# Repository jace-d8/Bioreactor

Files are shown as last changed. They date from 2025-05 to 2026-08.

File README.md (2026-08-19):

# BioReactor

This is the firmware for an Arduino Nano ESP32 controlling a 3-reactor bioreactor rig. Each reactor has its own pH and ORP probe (Atlas Scientific EZO boards) and its own pair of dosing valves. The firmware reads the probes on a fixed cadence, automatically doses acid or oxidizer when readings fall below configured thresholds, displays live data on a 20x4 LCD, logs everything to an SD card, and exposes a joystick-driven menu for probe calibration and valve control.

## What it does

On a 2-second cadence, the firmware:

1. Reads pH and ORP from each of the 3 reactors over I2C (6 EZO probes total).
2. Compares each reading to its threshold. If a probe reads below threshold, the corresponding dosing valve is enqueued.
3. The MCP23017 I/O expander services the queue. One valve fires at a time, opens for 10 seconds, then closes. The next queued valve waits 12 seconds after the previous fired before it can open.
4. Each valve has a 60-second cooldown after firing before it can be re-enqueued.
5. Each valve has a rolling error window: if a valve fires more than its allowed trigger count inside a 60-minute window, I latch an error lock on that valve so it stops firing until the user resets it from the menu.
6. Sensor readings are written to the SD card every 2 seconds, and individual valve events get logged as message rows.

The LCD shows live readings when idle. The joystick (analog Y axis + push switch) opens the menu, where you can calibrate any probe and toggle valve control.

The timestamp is synced on boot via WiFi. Currently, the WiFi connection is set to be automatically connected to Washington State University Guest WiFi (WSU Guest), an open WiFi that requires adding the Arduino Nano ESP32 MAC address to a whitelist. WiFi SSID and time zone can be changed in config.h.

## Hardware

| Component | Role |
|---|---|
| Arduino Nano ESP32 | Main MCU |
| MCP23017 I/O expander | Drives the 6 dosing valves over I2C |
| 6x Atlas Scientific EZO boards | 3 pH + 3 ORP probes, I2C |
| LCM2004A 20x4 LCD | I2C display (on `Wire1`) |
| SD card module | SPI logging |
| 2-axis analog joystick with switch | Menu input |
| 6x N-channel power MOSFETs | Switch the dosing solenoids |
| 12V DC supply + LM2596 buck converters | Power for the logic side and the valves |

## Pin assignments

All in [`Config.h`](src/BioReactor/Config.h):

| Pin | Purpose |
|---|---|
| `PIN_Y = 2` | Joystick Y axis (analog) |
| `PIN_SW = 5` | Joystick push switch (active-low, `INPUT_PULLUP`) |
| `LCD_PIN_SDA = 6` | LCD I2C SDA (`Wire1`) |
| `LCD_PIN_SCL = 7` | LCD I2C SCL (`Wire1`) |
| `SD_CHIP_SELECT = 21` | SD card SPI chip-select |

MCP23017 outputs:

| MCP pin | Valve |
|---|---|
| 0 | pH1 dosing valve |
| 1 | ORP1 dosing valve |
| 2 | pH2 dosing valve |
| 3 | ORP2 dosing valve |
| 4 | pH3 dosing valve |
| 5 | ORP3 dosing valve |

EZO I2C addresses (declared in [`Config.h`](src/BioReactor/Config.h) under `EzoAddresses`, instantiated in [`BioReactor.ino`](src/BioReactor/BioReactor.ino)):

| Probe | I2C address |
|---|---|
| pH1 / pH2 / pH3 | 99 / 101 / 103 |
| ORP1 / ORP2 / ORP3 | 98 / 100 / 102 |

## Configurables

In [`Config.h`](src/BioReactor/Config.h):

```cpp
namespace Thresholds
{
  const float PH_MINIMUM = 6.3f;   // dose acid if pH drops below
  const int   ORP_MINIMUM = -400;  // dose oxidizer if ORP drops below
}

namespace BusSpeeds
{
  const uint32_t I2C_HZ    = 100000UL;    // both Wire and Wire1
  const uint32_t SD_SPI_HZ = 1000000UL;   // SD card SPI clock
}

namespace JoystickConfig
{
  const int           ANALOG_CENTER       = 1980;    // analogRead center value
  const int           ANALOG_DEADZONE     = 400;     // counts above/below center before scrolling
  const unsigned long SCROLL_DELAY_MS     = 200UL;   // throttle between menu scrolls
  const unsigned long SWITCH_DEBOUNCE_MS  = 300UL;   // joystick push-button debounce
}

namespace EzoAddresses
{
  const int PH[3]  = {99, 101, 103};
  const int ORP[3] = {98, 100, 102};
}

namespace TimingIntervals
{
  const unsigned long PROBE_READ_INTERVAL = 2000UL;             // probe polling
  const unsigned long SD_LOG_INTERVAL     = 2000UL;             // SD write cadence
  const unsigned long VALVE_COOLDOWN      = 60UL * 1000UL;      // per-valve refire lockout
  const unsigned long VALVE_ERROR_WINDOW  = 60UL*60UL*1000UL;   // rolling error window
  const int PH_VALVE_TRIGGER_LIMIT  = 10;                       // max pH fires per window
  const int ORP_VALVE_TRIGGER_LIMIT = 20;                       // max ORP fires per window
  const int MAX_VALVE_ERROR_HISTORY = 20;                       // ring buffer size
  const unsigned long BLINK_INTERVAL      = 300UL;              // menu cursor blink
  const unsigned long UI_RENDER_INTERVAL  = 80UL;               // menu redraw cap (~12.5 FPS)
  const unsigned long EZO_READ_INTERVAL   = 900UL;              // EZO state-machine tick
  const unsigned long QUEUE_TIMER         = 12000UL;            // min gap between queue pops
  const unsigned long VALVE_TIMER         = 10000UL;            // how long a valve stays open
}
```

`VALVE_TIMER` and `QUEUE_TIMER` are read by [`Mcp.cpp`](src/BioReactor/Mcp.cpp) and control the dosing valve on-time and the inter-valve gap. To shorten a dose (e.g. for tighter NaOH or air control), reduce `VALVE_TIMER` and keep `QUEUE_TIMER` at least as large.

## Module map

| File | What it does |
|---|---|
| [`BioReactor.ino`](src/BioReactor/BioReactor.ino) | Top-level setup + main loop. Owns the `ConfigState`, the probe arrays, and the valve trigger history. |
| [`Config.h`](src/BioReactor/Config.h) | All pins, thresholds, timings, and the shared `ConfigState` struct. |
| [`EzoBoard.{h,cpp}`](src/BioReactor/EzoBoard.h) | Wraps the Atlas EZO I2C driver. Runs an async read state machine (`Reading -> Waiting -> Receiving`), holds the last valid value, and exposes `sendCmd()` for calibration. |
| [`Mcp.{h,cpp}`](src/BioReactor/Mcp.h) | Owns the MCP23017 and the dosing-valve queue. `enqueue()` adds a valve, `update()` services the queue (open one valve, wait `VALVE_TIMER`, close it, gate the next pop on `QUEUE_TIMER`). |
| [`Sd.{h,cpp}`](src/BioReactor/Sd.h) | SPI SD logger. Auto-generates a fresh `LOG####.CSV` at boot, writes timestamped sensor rows and message rows for valve events and lockouts. |
| [`Lcd.{h,cpp}`](src/BioReactor/Lcd.h) | I2C 20x4 driver wrapper. Live data view and menu rendering helpers. |
| [`Joystick.{h,cpp}`](src/BioReactor/Joystick.h) | Reads the analog Y axis with a dead zone, debounces the switch, holds the current menu selection and max index. |
| [`Menu.{h,cpp}`](src/BioReactor/Menu.h) | UI state machine (`Idle / Calibrating / Valves / PhCalibration / OrpCalibration / Off`). Probe calibration writes EZO `Cal,low/mid/high/clear` commands; valve menu toggles dosing on/off and resets error locks. |
| [`Timer.{h,cpp}`](src/BioReactor/Timer.h) | Interval timer: `isReady()` returns true once `interval` has elapsed since last `reset()`. |
| [`ActionTimer.h`](src/BioReactor/ActionTimer.h) | One-shot cooldown timer. `start()` arms it, `done()` reports whether the duration has elapsed. |
| [`Wifi.h`](src/BioReactor/Wifi.h) | Connects the system to Wifi and syncs time at boot. Writes the status of time sync to the log file |
## Logging format

Every row in `LOG####.CSV` has the header `timestamp,pH1,ORP1,pH2,ORP2,pH3,ORP3,message`.

- **Sensor rows** (every `SD_LOG_INTERVAL`): the 6 readings populated, message blank.
- **Event rows** (valve fires, lockouts, boot): sensor columns blank, message column populated. Examples:

```
2026-05-13 14:02:11,6.273,-412,6.95,-380,6.84,-405,
2026-05-13 14:02:13,,,,,,,pH1 valve was triggered
2026-05-13 14:02:13,,,,,,,BOOT
2026-05-13 14:03:47,,,,,,,ORP2 valve locked
```

## Boot sequence

`setup()` brings up `Wire` (EZO + MCP bus), `Wire1` (LCD bus), the MCP, the LCD, SPI, the system clock (`configTime`), and the SD logger. If either the MCP or the SD card fails to initialize I show the failure on the LCD instead of starting the main loop. On success I write a `BOOT` row to the log.

## Menu navigation

Push the joystick at any time from the idle screen to open the menu.

| Screen | Actions |
|---|---|
| **Main** | Calibrate Probes / Valve Control / Exit |
| **Calibrate Probes** | Pick pH1/2/3 or ORP1/2/3 to enter probe calibration, or Done to go back |
| **pH calibration** | `Cal,low,4.00`, `Cal,mid,7.00`, `Cal,high,10.00`, `Cal,clear`, Done. A `*` marks buffers already calibrated for the active probe. The live pH reading is shown at the bottom. |
| **ORP calibration** | `Cal,222` (single-point at 222 mV) or Done. The live ORP reading is shown at the bottom. |
| **Valve Control** | Toggle valves enabled/disabled globally, reset any latched valve error locks, or return. |

## Naming Conventions

| Item | Style | Example |
|---|---|---|
| Classes | PascalCase | `EzoBoard` |
| Functions | camelCase | `sendCmd()` |
| Variables | camelCase | `orpValue` |
| Private Members | trailing `_` | `lastTrigger_` |
| Constants | ALL_CAPS | `MAX_BUFFER_SIZE` |

## Dependencies

Install through the Arduino IDE Library Manager unless noted otherwise:

- **SD** by SparkFun
- **Adafruit MCP23017 Arduino Library** by Adafruit
- **I2C_LCD** by Rob Tillaart
- **LiquidCrystal I2C** by Frank de Barbander
- **Ezo_I2c_lib** by Atlas-Scientific. This one is not in the Library Manager. I downloaded it from the Atlas-Scientific GitHub page and installed it manually into the Arduino IDE.

In the Arduino IDE, under **Tools**, set Pin Numbering to **"By GPIO number (legacy)"**.

## Building

Open [`src/BioReactor/BioReactor.ino`](src/BioReactor/BioReactor.ino) in the Arduino IDE, select the Arduino Nano ESP32 board, set the pin numbering option above, and upload.

---

Jace Dunn  
Kuangs Biotech Group, WSU  
jace.dunn@wsu.edu

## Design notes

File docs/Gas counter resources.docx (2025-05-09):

Please keep this document confidential

## General concept

- Gas production pushes the liquid in a U-tube to touch a liquid level sensor
- The liquid level sensor signals Arduino to trigger a solenoid valve to open to the atmosphere, which resets the liquid level
- Each liquid level change and reset is a consistent known volume. Counting the times that liquid level is triggered gives the gas production volume

Step 1:

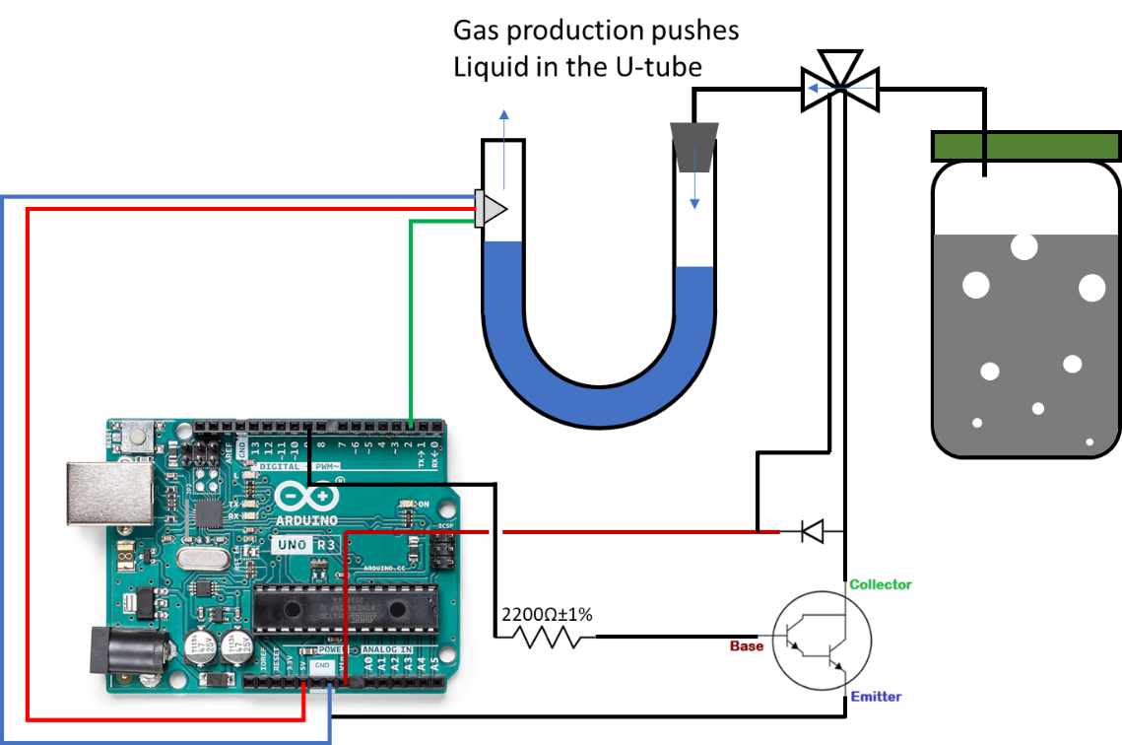
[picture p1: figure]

Step 2:

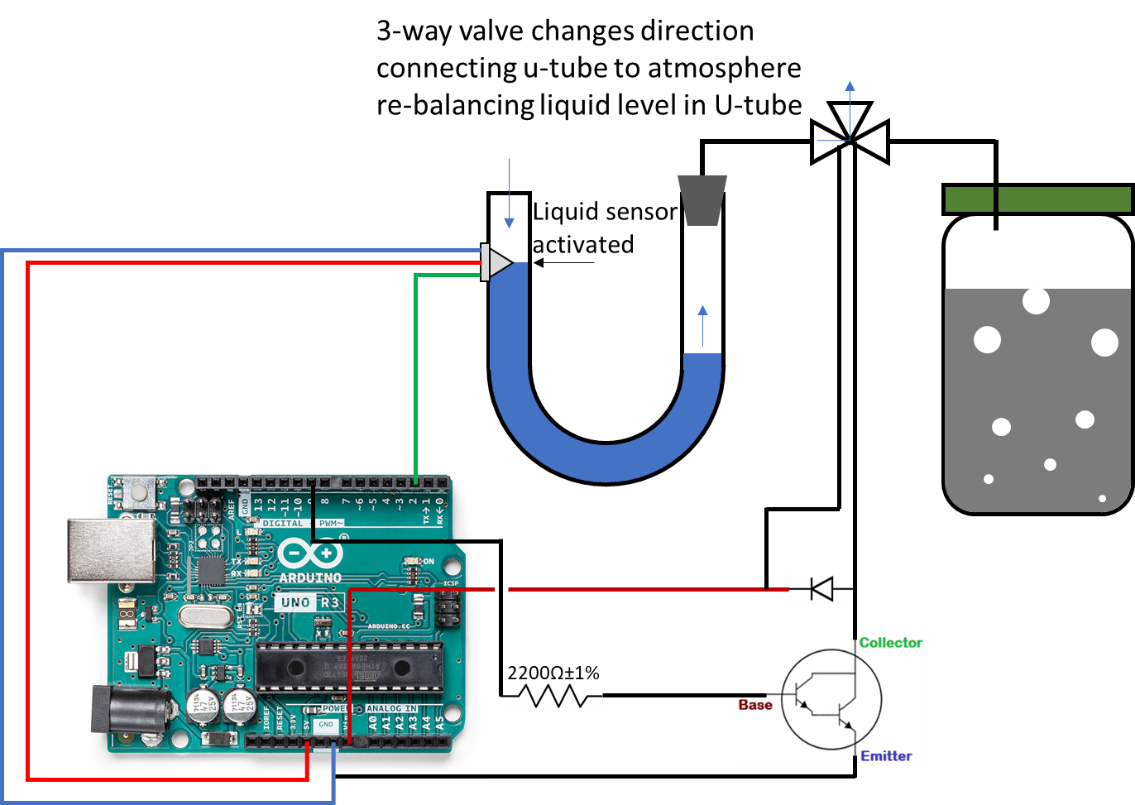
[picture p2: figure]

Step 3:

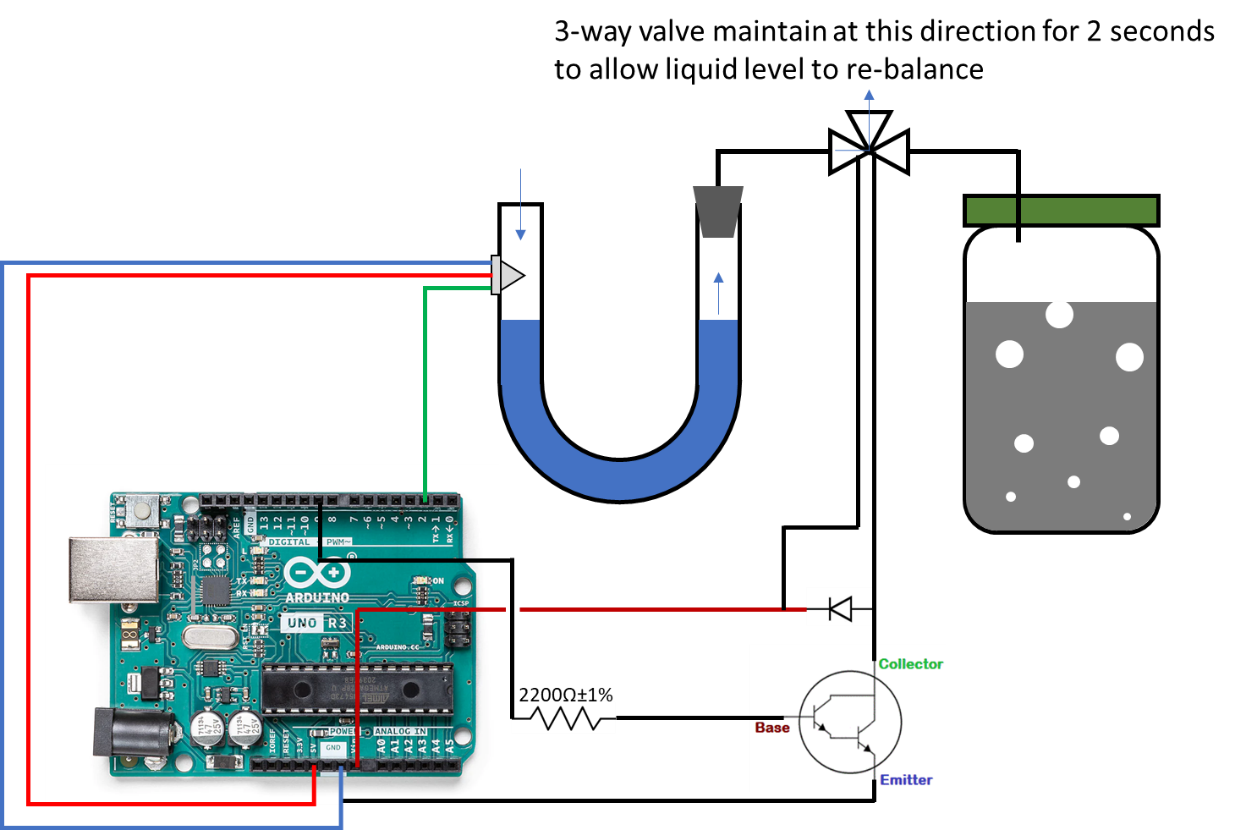
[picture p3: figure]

Step 4:

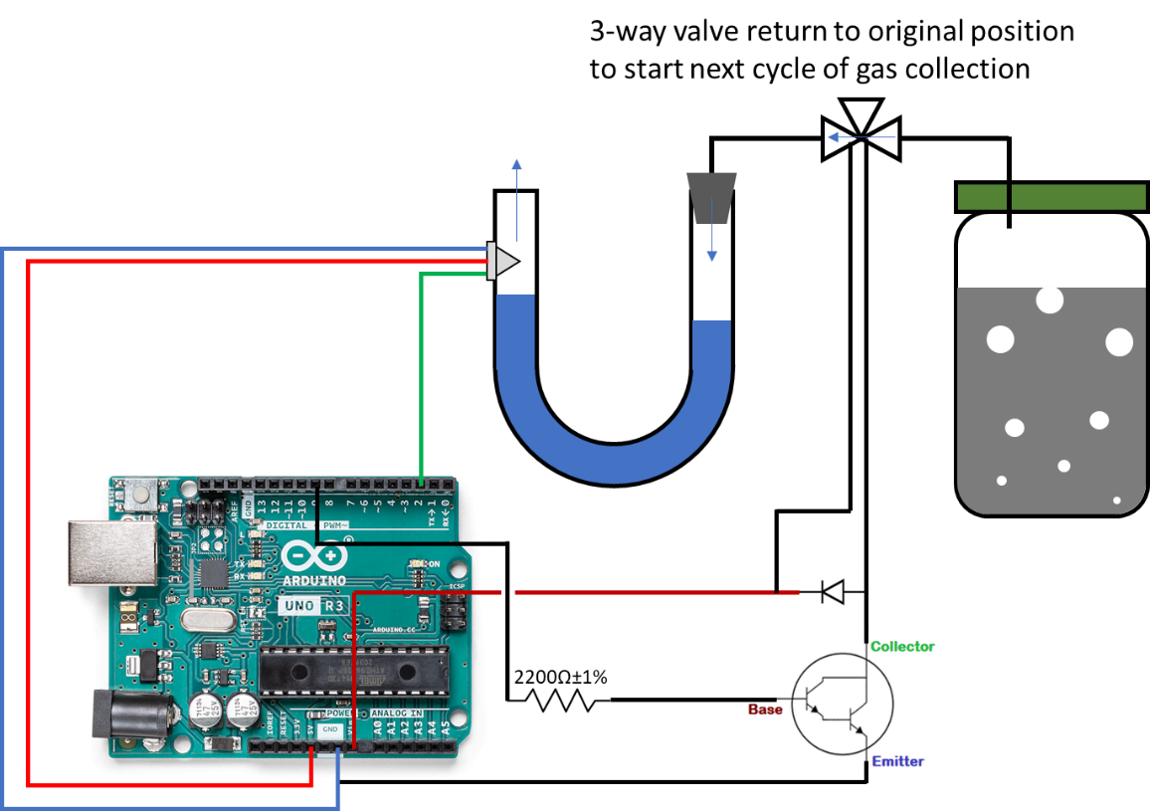
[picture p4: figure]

## Arduino board draft

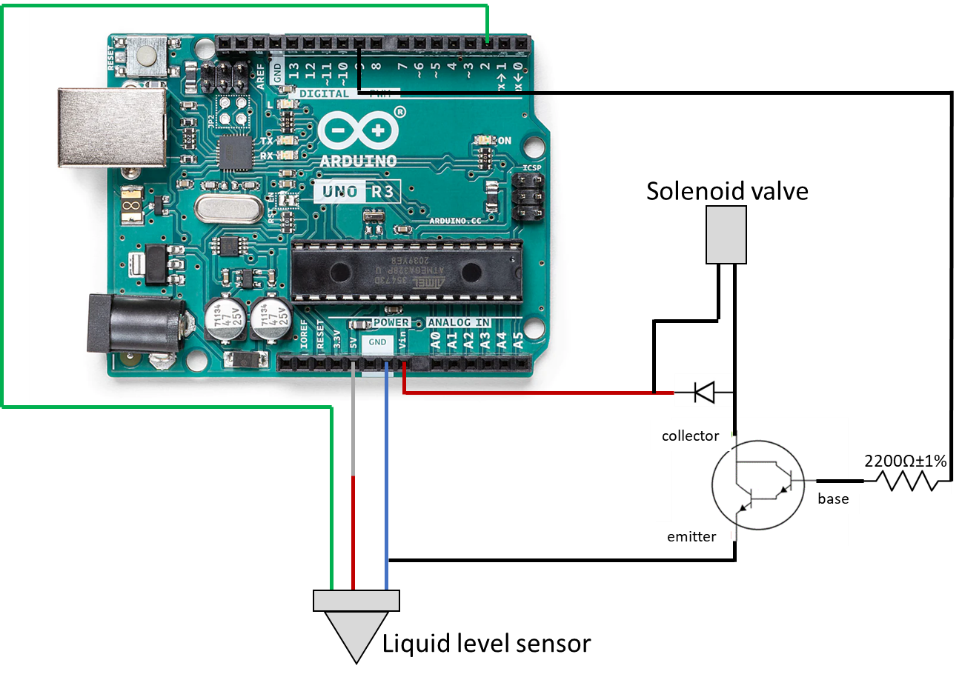
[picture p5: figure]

## Parts needed (some may be out of stock, need to find equivalents)

Must have:

- One level sensor ($25): Honeywell S&C - LLE101000 Adafruit: https://www.adafruit.com/product/3397
- One Solenoid Valve ($60): Asco 411M1312HV https://www.radwell.com/Buy/ASCO/ASCO/411M1312HV
- One Manifold ($28/pack of 4): clippart #15490-5 http://www.clippard.com/
- [Already in lab] One #10-32 to 1/8” ID Hose Fitting ($6/Pack of 10): #11752-3-PKG http://www.clippard.com/
- One Arduino Uno R3 (Atmega328 - assembled) ($24) #50 https://www.adafruit.com/
- One RGB LCD Shield Kit w/ 16x2 Character Display - Only 2 pins used! - NEGATIVE DISPLAY ($24) #714 https://www.adafruit.com/
- One TIP120 Power Darlington Transistors - 3 pack ($2.5) #976 https://www.adafruit.com/
- One 12 VDC 1000mA regulated switching power adapter - UL listed ($8) #798 https://www.adafruit.com/
- 1N4001 Diode - 10 pack ($1.5) #755 https://www.adafruit.com/
- Adafruit Perma-Proto Quarter-sized Breadboard PCB - Single ($3) #1608 https://www.adafruit.com/
- 2.2K Ohm Flameproof Electronic Metal Film Resistor ($8.67) Amazon: https://www.amazon.com/gp/product/B016D8CAB4/ref=crt_ewc_title_dp_3?ie=UTF8&psc=1&smid=ATVPDKIKX0DER

Good to have but optional

- One Quick-Disconnect Push-In Signal/Power Connector - Male ($26): McMaster #6134T43 https://www.mcmaster.com
- One Quick-Disconnect Push-In Signal/Power Connector - Female ($14): McMaster #6134T33 https://www.mcmaster.com
- Small Plastic Project Enclosure - Weatherproof with Clear Top ($10) #903 https://www.adafruit.com/

## Arduino Codes

// LCD library includes

#include <Wire.h>

#include <Adafruit_MCP23017.h>

#include <Adafruit_RGBLCDShield.h>

// Port definition

#define OPTO_PIN 2

#define VALVE_PIN 9

// LCD variable

Adafruit_RGBLCDShield lcd = Adafruit_RGBLCDShield();

// Other variables

int counter = 0;

bool open_valve = false;

void setup() {

// Initialize pin mode

pinMode(OPTO_PIN, INPUT);

pinMode(VALVE_PIN, OUTPUT);

Serial.begin(9600);

// set up the LCD's number of columns and rows:

lcd.begin(16, 2);

lcd.setBacklight(0x7);

lcd.setCursor(0,0);

lcd.print("Bio-Gas Counter");

lcd.setCursor(0,1);

lcd.print(counter);

//Serial.println(counter);

}

void loop() {

lcd.setCursor(0, 1);

// Read buttons status

uint8_t buttons = lcd.readButtons();

if (buttons & BUTTON_SELECT)

{

counter = 0;

lcd.print(counter);

}

if (buttons & BUTTON_LEFT) {

digitalWrite(VALVE_PIN,HIGH);

} else {

digitalWrite(VALVE_PIN,LOW);

}

gas_counter();

if(open_valve)

{

digitalWrite(VALVE_PIN,HIGH);

delay(2000);

digitalWrite(VALVE_PIN,LOW);

open_valve = false;

}

}

void gas_counter()

{

if(!digitalRead(OPTO_PIN))

{

counter++;

lcd.print(counter);

Serial.println(counter);

open_valve = true;

}

}

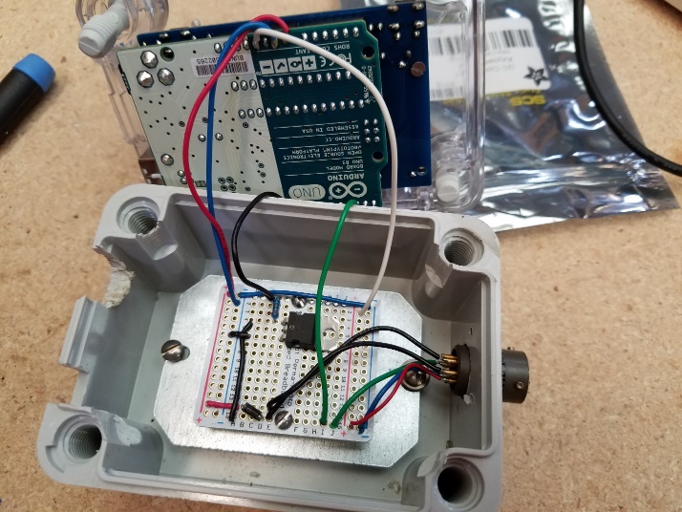
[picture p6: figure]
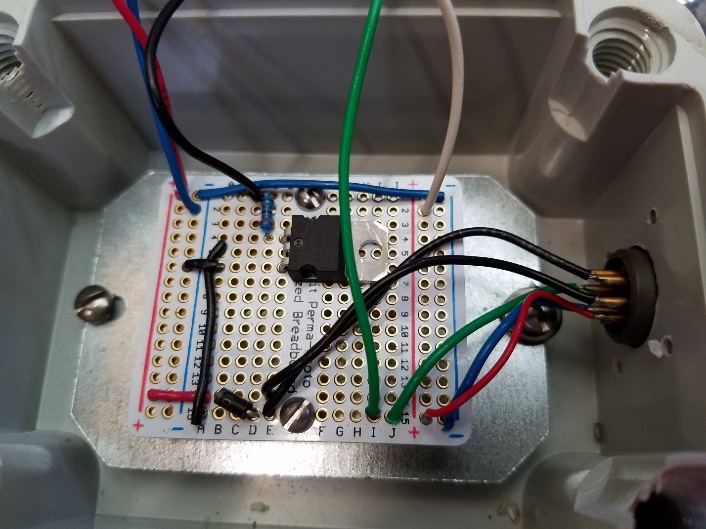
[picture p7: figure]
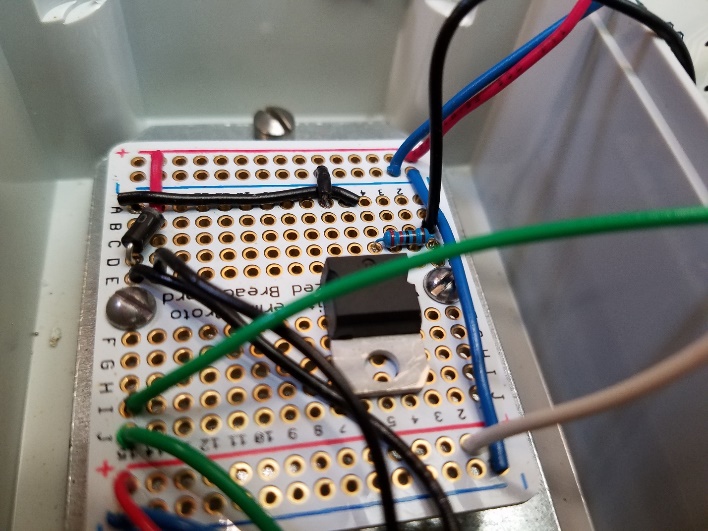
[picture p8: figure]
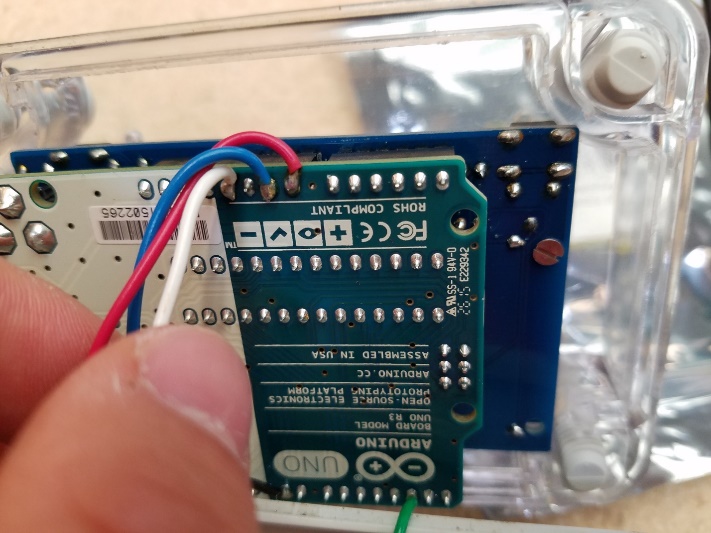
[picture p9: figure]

Overall reactor design for a two-phase system (just an idea for an old project, not necessary what we are developing here at WSU)

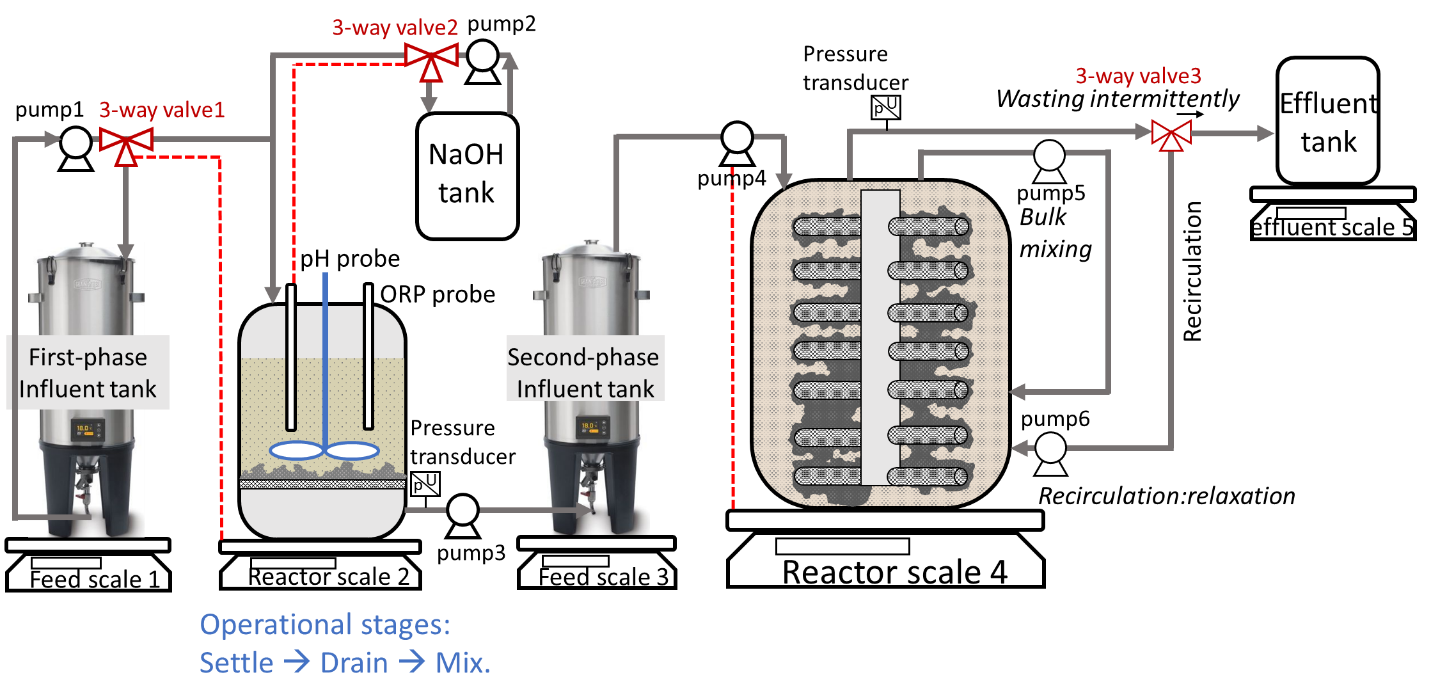
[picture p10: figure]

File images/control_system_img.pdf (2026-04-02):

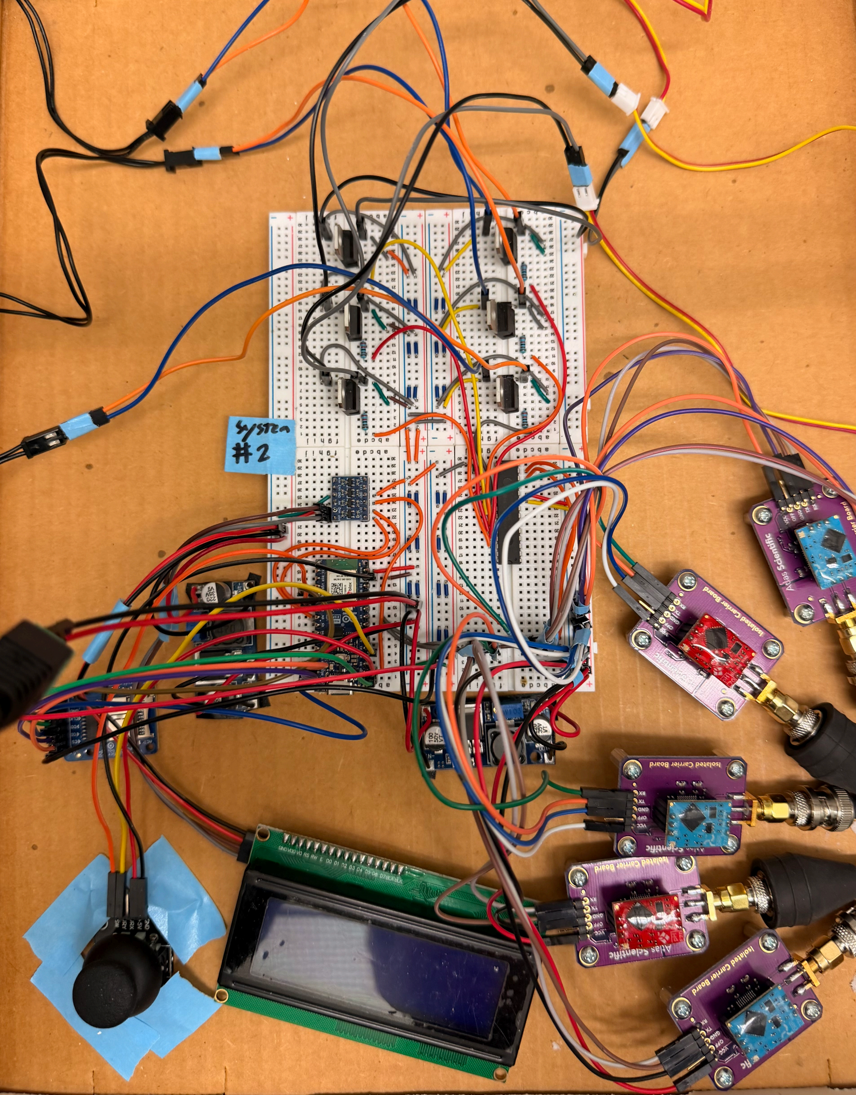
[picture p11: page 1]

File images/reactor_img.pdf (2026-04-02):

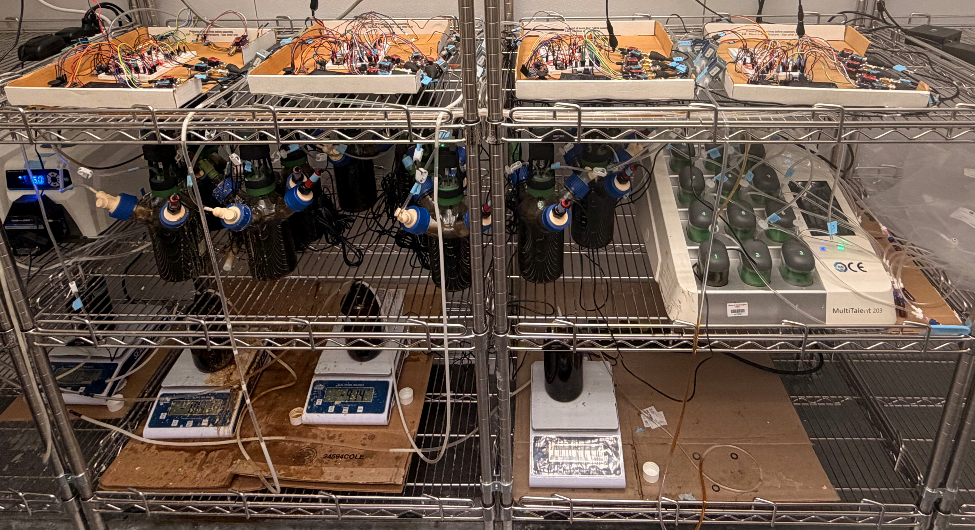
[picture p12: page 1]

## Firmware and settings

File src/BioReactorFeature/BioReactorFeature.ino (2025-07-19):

#include <Wire.h>
#include <Ezo_i2c.h>
#include <LiquidCrystal_I2C.h>
#include <SPI.h>
#include <SD.h>
#define UTC_OFFSET (-7 * 3600)  // For Pacific Time (PST). Use 0 for UTC, adjust as needed
#define PH_MIN 6.3
#define ORP_MIN -163


const int chipSelect = 10;
bool disableValves = false; 

File dataFile;


LiquidCrystal_I2C lcd(0x27, 20, 4);
char response[32];              // Buffer for response
String inputString = "";  // For manual commands

// Intervals
unsigned long lastReadTime = 0;
const unsigned long readInterval = 2000;  // 2 seconds
unsigned long lastHourTime = 0;
const unsigned long hourInterval = 3600000UL;  // 1 hour = 3,600,000 ms
unsigned long SDread = 0;
unsigned long pHread = 0;
unsigned long eLread = 0;
const unsigned long cooldownPeriod = 60000UL;

int phValveActivationCount = 0;
const int phValveMaxActivations = 5;
unsigned long lastPHactivation = 0;
const unsigned long phResetWindow = 15 * 60 * 1000UL; // 15 minutes to reset count

// Analog stick
const int SW_pin = D2; // D2: input for detecting whether the jotstick/button is pressed
const int Y_pin = A1; // A1: analog pin connected to Y output 

class Valve{
private: 
  int pin; 
  bool isOpen; 
  bool enable; 
  unsigned int startTime;
  const unsigned long openDuration; 
public: 
  Valve(int p, unsigned long d) : pin(p), openDuration(d), isOpen(false), enable(true), startTime(0) {}

  void open()
  {
    if(!isOpen && enable)
    {
      digitalWrite(pin, HIGH);
      startTime = millis(); 
      isOpen = true;
    } 
  }
  void update()
  {
    if (isOpen && (millis() - startTime >= openDuration))
    {
      digitalWrite(pin, LOW);
      isOpen = false;
    }
  }
  bool isValveOpen()
  {
    return isOpen;
  }
  void switchValve()
  {
    enable = !enable;
  }
  bool isEnabled()
  {
    return enable; 
  }
};

void logToSD(String message = "");


bool isCleared = false;
bool blinkState = true;
unsigned long lastBlinkTime = 0;
const unsigned long blinkInterval = 300;

// Probes
Ezo_board orp_sensor(98, "ORP");  
Ezo_board ph_sensor(99, "PH");  

// Probe Vals
float ph_val = 0.0; // I want these globally avaliable
int orp_val = 0; 

// Valves
Valve pHvalve(3, 10000);
Valve eLvalve(4, 4000);

// Note: I will consider using classes for further modularization

void setup()
{
  Serial.begin(9600);
  Wire.setClock(1000000);  // Set I2C speed to 100kHz


  pinMode(3, OUTPUT);  // For pHvalve
  pinMode(4, OUTPUT);  // For eLvalve
  
  // pinMode(LIQUID_SENSOR_PIN, INPUT);  
  // pinMode(GAS_SENSOR_PIN, INPUT); // Liquid detection sensor in U-tube
  // pinMode(VALVE_PIN, OUTPUT); // Controls state of 3 way valve

  //pinMode(SW_pin, INPUT); // Setup SW input
  //digitalWrite(SW_pin, HIGH);  // Reading button state: 1 = not pressed, 0 = pressed
  // The above two lines are for normal arduino, the below is for the nano esp32
  pinMode(SW_pin, INPUT_PULLUP);  
  //delay(100);

  Wire.begin();       
  lcd.init();
  lcd.backlight();
  lcd.setCursor(0, 0);
  lcd.print("Reading Probes");
  lcd.setCursor(0, 1);
  
  if (SD.begin(chipSelect)) 
  {
    lcd.print("SD initilzed");
    dataFile = SD.open("/data.csv", FILE_WRITE);
    dataFile.println("DATE,PH,ORP");
  }else
  {
    lcd.print("SD failed");
  }
  lcd.setCursor(0, 2);
  configTime(UTC_OFFSET, 0, "");  
  setTimeFromBuild();
}

void loop() 
{
  // is_liquid_detected = digitalRead(LIQUID_SENSOR_PIN); // will become true if sensor detects liquid 
  // is_gas_sensor = digitalRead(GAS_SENSOR_PIN); // is_open will be true if high voltage is read
  if (isCooldownOver(readInterval, lastReadTime)) 
  {
    ph_val = readPH();  // Convert char* to float
    orp_val = readORP();
    if(!isCleared)
    {
      lcd.clear(); // consider optimizing
      isCleared = true;
    }
    printData();   
    lastReadTime = millis();
  }

  if(isCooldownOver(SDread, 6000)) // 2 min, will change later
  {
    logToSD(); 
    SDread = millis(); 
  }
  if ((ph_val < PH_MIN) && isCooldownOver(pHread, cooldownPeriod)) 
  {
    pHvalve.open();
    logToSD("pH valve toggled"); 
    pHread = millis(); 

    // Check time since last activation
    if (millis() - lastPHactivation > phResetWindow) 
    {
      phValveActivationCount = 1;  // reset count
    }else 
    {
      phValveActivationCount++;  // count up
    }
    lastPHactivation = millis();
    if (phValveActivationCount >= phValveMaxActivations) 
    {
      displayWarning();  // trigger user intervention
      phValveActivationCount = 0;  // reset after warning
    }
  }
  if((orp_val < ORP_MIN) && isCooldownOver(eLread, cooldownPeriod)) // COOLDOWN DOES NOT CURRENTLY ACCOUNT FOR 10 SECONDS OF ACTIVATION, 50 second cooldown
  {
    eLvalve.open();
    logToSD("ORP valve toggled"); 
    eLread = millis(); 
  }
  if (isCooldownOver(lastHourTime, hourInterval))  
  {
    eLvalve.open();
    lastHourTime = millis();
  }

  pHvalve.update();
  eLvalve.update(); 
  lcdMenu();
}

bool isCooldownOver(unsigned long lastTime, unsigned long cooldown)
{
 return (millis() - lastTime >= cooldown);
}

float readPH()
{
  ph_sensor.send_cmd("R");         // Send read command
  delay(900);                      // Wait for the sensor to respond
  ph_sensor.receive_cmd(response, 32);  // Read response into buffer
  return atof(response);
}

float readORP()
{
  orp_sensor.send_cmd("R");
  delay(900);
  orp_sensor.receive_cmd(response, 32);
  return atof(response);
}


// void liquidLevelCheck(bool is_liquid_detected)
// {
//   if(is_liquid_detected)
//   {
//     Serial.println("Liquid detected");
//   }else
//   {
//     Serial.println("No liquid detected");
//   }
// }

// void gasCounter(bool is_gas_sensor)
// {
//   if (!is_gas_sensor && !valveOpen)
//   {
//     counter++;
//     Serial.println(counter);
//     digitalWrite(VALVE_PIN, HIGH);
//     valveStartTime = millis();
//     valveOpen = true;
//   }

//   if (valveOpen && millis() - valveStartTime >= interval) // maybe replace millis - valve with (lastprint)
//   {
//     digitalWrite(VALVE_PIN, LOW);
//     valveOpen = false;
//   }
// }

void lcdMenu()
{
  bool calibrateMenu = false;
  int selectedItem = -1;  // 0 = pH Probe 1, 1 = pH Probe 2...
  if(!digitalRead(SW_pin))
  {
    delay(200);  // debounce
    calibrateMenu = true; 
    selectedItem = 0;
    lcd.clear();
    while(calibrateMenu)
    {
      analogControl(selectedItem);
      updateGlobalBlink();

      lcd.setCursor(0, 0);
      lcd.print("Calibrate Probe:");

      printMenu(selectedItem);
      isPressed(calibrateMenu, selectedItem);
    }
  }
}

void printMenu(int selectedItem)
{
    printMenuItem(0, 1, "pH 1", 0, selectedItem);
    printMenuItem(0, 2, "pH 2", 1, selectedItem);
    printMenuItem(0, 3, "pH 3", 2, selectedItem);
    printMenuItem(6, 1, "ORP 1", 3, selectedItem);
    printMenuItem(6, 2, "ORP 2", 4, selectedItem);
    printMenuItem(6, 3, "ORP 3", 5, selectedItem);
    if(disableValves)
    {
      printMenuItem(13, 1, "Vl ON", 6, selectedItem);
    }else
    {
      printMenuItem(13, 1, "Vl OFF", 6, selectedItem);
    }

    printMenuItem(13, 2, "Done", 7, selectedItem);
}

void isPressed(bool &calibrateMenu, int selectedItem) // later to be optimized when multiple probes are utilized
{
  if (!digitalRead(SW_pin)) 
  {
    delay(200);  // debounce
    while (!digitalRead(SW_pin));  // wait until released
    if (selectedItem == 0)
    {
      calibrateProbePH();
    }else if(selectedItem == 3)
    {
      calibrateProbeORP();
    }else if(selectedItem == 6)
    {
      disableValves = !disableValves;
      pHvalve.switchValve();
      eLvalve.switchValve();
      lcd.clear();
      if(disableValves)
      {
        lcd.print("Valves off");
      }else
      {
        lcd.print("Valves on");
      }
      delay(600);
      lcd.clear();
    }else if (selectedItem == 7) 
    {
      calibrateMenu = false;
      lcd.clear();
    }
  }
}

void analogControl(int& selectedItem)
{
  int yVal = analogRead(Y_pin);

  // Dead zone around the resting value (~1980)
  const int deadZone = 400;

  if (yVal < 1980 - deadZone) 
  {  // Up
    if (selectedItem > 0)
      selectedItem--;
    delay(200); // Debounce
  } else if (yVal > 1980 + deadZone) 
  {  // Down
    if (selectedItem < 7)  // 6 is your "Done" item
      selectedItem++;
    delay(200); // Debounce
  }
}


void updateGlobalBlink() {
  unsigned long currentMillis = millis();
  if (currentMillis - lastBlinkTime >= blinkInterval) {
    blinkState = !blinkState;
    lastBlinkTime = currentMillis;
  }
}

void printMenuItem(int col, int row, const char* label, int itemIndex, int selectedIndex) {
  lcd.setCursor(col, row);
  if (itemIndex == selectedIndex && blinkState) {
    lcd.print("      ");  // Blank line to simulate blinking
  } else {
    lcd.print(label);
  }
}

void calibrateProbePH() {
  int bufferSelection = 0;
  bool bufferCalibrated[3] = {false, false, false};
  bool selecting = true;

  lcd.clear();

  while (selecting) {
    analogControl(bufferSelection);
    updateGlobalBlink();

    // ph_val = readPH();   putting this on hold

    lcd.setCursor(0, 0);
    lcd.print("Select Buffer:");
    printMenuItem(0, 1, "pH 4", 0, bufferSelection);
    printMenuItem(0, 2, "pH 7", 1, bufferSelection);
    printMenuItem(0, 3, "pH 10", 2, bufferSelection);
    printMenuItem(10, 1, "Clear", 3, bufferSelection);  
    printMenuItem(10, 2, "Done", 4, bufferSelection);
    lcd.setCursor(10, 3);
    // lcd.print("pH: ");
    // lcd.print(ph_val, 3); // to the thousandths


    if (bufferCalibrated[0]) lcd.setCursor(6, 1), lcd.print("*");
    if (bufferCalibrated[1]) lcd.setCursor(6, 2), lcd.print("*");
    if (bufferCalibrated[2]) lcd.setCursor(6, 3), lcd.print("*");

    
    if (!digitalRead(SW_pin)) {
      delay(200);
      while (!digitalRead(SW_pin)); 

      switch (bufferSelection) {
        case 0:
          ph_sensor.send_cmd("Cal,low,4.00");
          bufferCalibrated[0] = true;
          break;
        case 1:
          ph_sensor.send_cmd("Cal,mid,7.00");
          bufferCalibrated[1] = true;
          break;
        case 2:
          ph_sensor.send_cmd("Cal,high,10.00");
          bufferCalibrated[2] = true;
          break;
        case 3: 
          ph_sensor.send_cmd("Cal,clear");
          bufferCalibrated[0] = bufferCalibrated[1] = bufferCalibrated[2] = false;
          lcd.clear();
          lcd.print("Calibration Cleared");
          delay(1500);
          lcd.clear();
          break;
        case 4:  
          lcd.clear();
          lcd.print("Returning");
          delay(1000);
          lcd.clear();
          selecting = false;
          break;
      }
    }
    if (bufferCalibrated[0] && bufferCalibrated[1] && bufferCalibrated[2]) 
    {
      lcd.clear();
      lcd.print("All Calibrated!");
      delay(800);
      lcd.clear();
      selecting = false;
    }
  }
}

void calibrateProbeORP()
{
  int selectedItem = 0;  // Only one item for now, but this keeps it consistent
  bool selecting = true;
  int lastPrint = 0;
  lcd.clear();

  while (selecting) {
    analogControl(selectedItem);
    updateGlobalBlink();

    // if(isCooldownOver(lastPrint, 4000)) // 4 second cooldown
    // {
    //   orp_val = readORP(); putting this idea on hold
    // }
    lcd.setCursor(0, 0);
    lcd.print("Calibrate when ready");

    printMenuItem(0, 1, "Cal", 0, selectedItem);
    printMenuItem(0, 2, "Done", 1, selectedItem);

    lcd.setCursor(5, 1);

    // lcd.print("ORP: ");
    // lcd.print(orp_val, 0);
    // lcd.print(" mV     ");
    


    if (!digitalRead(SW_pin)) {
      delay(200);  // Debounce
      while (!digitalRead(SW_pin));  // Wait until released
      switch(selectedItem)
      {
        case 0:
          orp_sensor.send_cmd("Cal,222");
          lcd.clear();
          lcd.print("Calibrated at 222mV");
          delay(1000);
          selecting = false;
          lcd.clear();
          break;
        case 1: 
          lcd.clear();
          lcd.print("Returning");
          delay(1000);
          selecting = false;
          lcd.clear();
      }
    }
  }
}

void setTimeFromBuild()
{
  struct tm tm; // std C++ time struct
  if (strptime(__DATE__ " " __TIME__, "%b %d %Y %H:%M:%S", &tm)) // Taking compile time and parsing it for tm 
   {
    time_t t = mktime(&tm); // unix timestamp 
    struct timeval now = { .tv_sec = t }; // std C++ time struct, seconds since 1970, so esp32 can count further
    settimeofday(&now, nullptr); // setting esp32 clock to laptop time

    char buf[32];
    strftime(buf, sizeof(buf), "%Y-%m-%d %H:%M:%S", localtime(&t)); // takes seconds and converts to human readable time
    lcd.print(buf);
  } else 
  {
    lcd.print("Failed to parse build time");
  }
}

void logToSD(String message)
{
  time_t now = time(nullptr);
  struct tm* timeinfo = localtime(&now); // reads our updated esp32 time

  if (!dataFile) 
  {
    lcd.print("File failed\n");
    return;
  }
  if (message.length() == 0) 
  {
    dataFile.printf("%04d-%02d-%02d %02d:%02d:%02d,%.3f,%d\n", // logging time from esp32
                    timeinfo->tm_year + 1900,
                    timeinfo->tm_mon + 1,
                    timeinfo->tm_mday,
                    timeinfo->tm_hour,
                    timeinfo->tm_min,
                    timeinfo->tm_sec,
                    ph_val,
                    orp_val);
    dataFile.flush();
  }
  else
  {
    dataFile.printf("%04d-%02d-%02d %02d:%02d:%02d,%s\n",
                    timeinfo->tm_year + 1900,
                    timeinfo->tm_mon + 1,
                    timeinfo->tm_mday,
                    timeinfo->tm_hour,
                    timeinfo->tm_min,
                    timeinfo->tm_sec,
                    message.c_str());   
  }         
}

void displayWarning()
{
  bool bypass_warning = false; 
  lcd.clear();
  pHvalve.switchValve();
  while(!bypass_warning)
  {
    updateGlobalBlink();

    lcd.setCursor(0, 0);
    lcd.print("WARNING:");
    
    lcd.setCursor(0, 1);
    lcd.print("pH valve overuse");

    printMenuItem(0, 2, "Unlock?", 0, 0);

    if (!digitalRead(SW_pin)) 
    {
      delay(200);
      while (!digitalRead(SW_pin)); 
      bypass_warning = true;
      lcd.clear();
      lcd.print("System Unlocked");
      delay(700);
      lcd.clear();
      pHvalve.switchValve();
    }
  }
}

void printData()
{
    lcd.setCursor(0, 0);
    lcd.print("pH: ");
    lcd.print(ph_val, 3); // To the thousandths
    lcd.print("     "); // Clear leftover digits

    lcd.setCursor(0, 1);
    lcd.print("ORP: ");
    lcd.print(orp_val, 0);
    lcd.print(" mV     ");

    // lcd.setCursor(0, 2);
    // lcd.print("Count: ");
    // lcd.print(counter);  
    // lcd.print("     ");
}

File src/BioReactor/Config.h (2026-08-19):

#pragma once
#include <Arduino.h>

namespace PinConfigurations
{
  const int PIN_SW = 5;//Joystick switch pin//
  const int PIN_Y = 2;//Joystick y-axis pin//
  const int PH_VALVE_PIN = 10;//pH valve pin, no longer used since all valves are handled in MCP//
  const int ORP_VALVE_PIN = 17;//ORP valve pin, no longer used since all valves are handled in MCP// 
  const int LCD_PIN_SDA = 6;//LCD SDA pin//
  const int LCD_PIN_SCL = 7;//LCD SCL pin//
  const int SD_CHIP_SELECT = 21;//SD chip select pin//
}

namespace ThresholdDefaults
{
  const float PH_MINIMUM = 4.1f; //normally 6.3, set to 4.1 for testing//
  const float ORP_MINIMUM = -400.0f; // use -400 for microaerobic trials, use -1000 for anaerobic trials //
}

namespace ThresholdLimits
{
  const float PH_MIN = 4.0f;
  const float PH_MAX = 9.0f;
  const float PH_STEP = 0.1f;
  const float ORP_MIN = -500.0f;
  const float ORP_MAX = 500.0f;
  const float ORP_STEP = 5.0f;
}

namespace BusSpeeds//Bus speeds for I2C and SPI//
{
  const uint32_t I2C_HZ = 100000UL;//I2C bus speed//
  const uint32_t SD_SPI_HZ = 1000000UL;//SPI bus speed for SD card//
}

namespace JoystickConfig//Joystick configuration//
{
  const int ANALOG_CENTER = 1980;//Analog center value//
  const int ANALOG_DEADZONE = 800;//Analog deadzone value, within which the joystick is considered to be in the center position//
  const unsigned long SCROLL_DELAY_MS = 200UL;//Scroll delay time, to prevent rapid scrolling//
  const unsigned long SWITCH_DEBOUNCE_MS = 300UL;//Switch debounce time, to prevent rapid button presses//
}

namespace EzoAddresses//EZO addresses for the 3 probes//
{
  const int PH[3]  = {99, 101, 103};//pH probe addresses//
  const int ORP[3] = {98, 100, 102};//ORP probe addresses//
}

namespace TimingIntervals
{
  const unsigned long PROBE_READ_INTERVAL = 2000UL;//*2 seconds between probe reads//
  const unsigned long SD_LOG_INTERVAL = 30000UL;//*30 seconds between SD card logs//

  const unsigned long VALVE_COOLDOWN = 60UL * 1000UL;//*60 s cooldown between valve triggers//

  // Separate error-lock windows for pH and ORP valves.
  // Each defines how far back the trigger history is scanned when deciding
  // whether a valve has exceeded its trigger limit.  Having two independent
  // constants means the pH and ORP windows can be tuned separately in
  // Config.h without affecting each other.
  const unsigned long PH_VALVE_ERROR_WINDOW  = 60UL * 60UL * 1000UL;//*1 hour window for pH error-locking//
  const unsigned long ORP_VALVE_ERROR_WINDOW = 60UL * 60UL * 1000UL;//*1 hour window for ORP error-locking//

  const int MAX_VALVE_ERROR_HISTORY = 99;

  const unsigned long BLINK_INTERVAL = 300UL;//*300 ms between blink state changes//
  const unsigned long UI_RENDER_INTERVAL = 80UL;//*80 ms between UI renders//

  const unsigned long EZO_READ_INTERVAL = 900UL;//*900 ms between probe reads//
  const unsigned long EZO_EXPORT_IMPORT_DELAY = 1800UL; //*1800 ms delay per calibration data import chunk//
  const unsigned long EZO_CAL_SETTLE_MS = 1000UL; //*1000 ms gap after a Cal command before export begins; the EZO has no command queue so Export must not be sent until Cal has fully executed (~900 ms)//

  // Default valve open durations (seconds); editable at runtime via Thresholds menu//
  const int PH_VALVE_TIMER_SEC  = 10;//*10 s default pH valve open duration//
  const int ORP_VALVE_TIMER_SEC = 10;//*10 s default ORP valve open duration//

  // Queue timers are always valve-timer + 2 s; recomputed at runtime in BioReactor.ino//
  // These compile-time constants give the startup values before any menu edits.//
  const unsigned long PH_VALVE_TIMER  = (unsigned long)PH_VALVE_TIMER_SEC  * 1000UL;
  const unsigned long ORP_VALVE_TIMER = (unsigned long)ORP_VALVE_TIMER_SEC * 1000UL;
  const unsigned long PH_QUEUE_TIMER  = PH_VALVE_TIMER  + 2000UL;
  const unsigned long ORP_QUEUE_TIMER = ORP_VALVE_TIMER + 2000UL;

  // How long a reading must stay below threshold before the valve is queued//
  const unsigned long VALVE_BELOW_THRESHOLD_MS = 10000UL;//*10 s dwell before queueing//
}

namespace TriggerLimitDefaults
{
  const int PH_VALVE_TRIGGER_LIMIT  = 5;//max 5 pH valve triggers per hour (default)//
  const int ORP_VALVE_TRIGGER_LIMIT = 73;//max 73 ORP valve triggers per hour (default)//
}

namespace TriggerLimitBounds
{
  const int MIN  = 1;
  const int MAX  = 99;
  const int STEP = 1;
}

namespace ValveTimerBounds
{
  const int MIN_SEC  = 1;
  const int MAX_SEC  = 18;  //cannot exceed 18 seconds or it will conflict with the 1min cooldown.//
  const int STEP_SEC = 1;
}

namespace ValveMappings//Mapping of MCP pins to valves//
{
  const int TOTAL_VALVES = 6;
}

namespace CalibrationStorage
{
  const char FILE_PATH[] = "/CALIB.CSV";
  const size_t EXPORT_PAYLOAD_MAX = 160;
}
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

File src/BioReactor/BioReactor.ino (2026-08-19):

#include <Wire.h>
#include <SPI.h>
#include <string.h>
#include "Config.h"
#include "Mcp.h"
#include "EzoBoard.h"
#include "Lcd.h"
#include "Sd.h"
#include "Timer.h"
#include "ActionTimer.h"
#include "Menu.h"
#include "Wifi.h"

ConfigState config;
WifiTime wifiTime;//non-blocking WiFi connect + NTP sync, keeps the clock correct across power cycles//

EzoBoard orpSensors[3] = {//set up ORP sensors (3 probes)//
  EzoBoard(EzoAddresses::ORP[0], "ORP"),
  EzoBoard(EzoAddresses::ORP[1], "ORP"),
  EzoBoard(EzoAddresses::ORP[2], "ORP")
};

EzoBoard phSensors[3] = {//set up pH sensors (3 probes)//
  EzoBoard(EzoAddresses::PH[0], "pH"),
  EzoBoard(EzoAddresses::PH[1], "pH"),
  EzoBoard(EzoAddresses::PH[2], "pH")
};

Mcp mcp;//set up MCP controller (controls the valves)//
Lcd lcd(0x27, &Wire1);//set up LCD display//
SdLogger sd;//set up SD card logger//
Menu menu(&config, phSensors, orpSensors, lcd, sd, wifiTime);

Timer probeTimer(TimingIntervals::PROBE_READ_INTERVAL);//*2 s between probe reads//
Timer sdLogTimer(TimingIntervals::SD_LOG_INTERVAL);//*2 s between SD card logs//

bool queued[ValveMappings::TOTAL_VALVES] = { false };//valve already in queue guard//

ActionTimer cooldown[ValveMappings::TOTAL_VALVES] = {
  ActionTimer(TimingIntervals::VALVE_COOLDOWN),
  ActionTimer(TimingIntervals::VALVE_COOLDOWN),
  ActionTimer(TimingIntervals::VALVE_COOLDOWN),
  ActionTimer(TimingIntervals::VALVE_COOLDOWN),
  ActionTimer(TimingIntervals::VALVE_COOLDOWN),
  ActionTimer(TimingIntervals::VALVE_COOLDOWN)
};//One 60 s cooldown timer per valve; started when a valve is queued.//

// ── Dwell timers ──────────────────────────────────────────────────────────────
// Each valve gets its own ActionTimer.  The timer is started (or kept running)
// while the reading is below the threshold, and reset as soon as the reading
// rises above it.  A valve is only queued once the dwell timer has expired,
// i.e. the reading has been continuously below threshold for at least
// TimingIntervals::VALVE_BELOW_THRESHOLD_MS milliseconds.
ActionTimer dwellTimer[ValveMappings::TOTAL_VALVES] = {
  ActionTimer(TimingIntervals::VALVE_BELOW_THRESHOLD_MS),
  ActionTimer(TimingIntervals::VALVE_BELOW_THRESHOLD_MS),
  ActionTimer(TimingIntervals::VALVE_BELOW_THRESHOLD_MS),
  ActionTimer(TimingIntervals::VALVE_BELOW_THRESHOLD_MS),
  ActionTimer(TimingIntervals::VALVE_BELOW_THRESHOLD_MS),
  ActionTimer(TimingIntervals::VALVE_BELOW_THRESHOLD_MS)
};

// Tracks whether each valve's dwell timer is currently running (started but
// not yet done).  Prevents re-starting the timer on every loop iteration.
bool dwellRunning[ValveMappings::TOTAL_VALVES] = { false };

//History of open times for error-locking (too many opens in *1 hour).//
unsigned long valveTriggerTimes[ValveMappings::TOTAL_VALVES][TimingIntervals::MAX_VALVE_ERROR_HISTORY] = {};
int valveTriggerCounts[ValveMappings::TOTAL_VALVES] = {};

// ── tryQueueValve ─────────────────────────────────────────────────────────────
// condition = true  → reading is below threshold right now.
// A valve is only actually queued once the dwell timer says the reading has
// been below threshold for at least VALVE_BELOW_THRESHOLD_MS continuously.
bool tryQueueValve(int valveId, bool condition)
{
  if (!condition)
  {
    // Reading is fine — reset the dwell timer so the clock starts fresh
    // if it dips below threshold again later.
    dwellTimer[valveId].stop();
    dwellRunning[valveId] = false;
    return false;
  }

  // Reading is below threshold.  Kick off the dwell timer on the first
  // low reading.  dwellRunning[] tracks whether we have already called
  // start() so we do not reset a running timer on every loop iteration.
  if (!dwellRunning[valveId])
  {
    dwellTimer[valveId].start();
    dwellRunning[valveId] = true;
  }

  // Not yet held below threshold long enough.
  if (!dwellTimer[valveId].done()) return false;

  // Dwell satisfied — now apply the usual guards.
  if (config.valvesDisabled)               return false;
  if (queued[valveId])                     return false;
  if (config.valveErrorLocked[valveId])    return false;
  if (!cooldown[valveId].done())
  {
    // Cooldown still running — reset dwell so the 5 s must elapse
    // again from scratch once the cooldown is over.
    dwellTimer[valveId].stop();
    dwellRunning[valveId] = false;
    return false;
  }
  if (!mcp.enqueue(valveId))               return false;

  cooldown[valveId].start();
  queued[valveId] = true;

  // Reset dwell so the timer must expire again for the next trigger.
  dwellTimer[valveId].stop();
  dwellRunning[valveId] = false;

  return true;
}

// ── recordValveTrigger ────────────────────────────────────────────────────────
void recordValveTrigger(int valveId)
{
  int& count = valveTriggerCounts[valveId];

  if (count < TimingIntervals::MAX_VALVE_ERROR_HISTORY)
  {
    valveTriggerTimes[valveId][count++] = millis();
  }
  else
  {
    for (int i = 1; i < TimingIntervals::MAX_VALVE_ERROR_HISTORY; ++i)
      valveTriggerTimes[valveId][i - 1] = valveTriggerTimes[valveId][i];
    valveTriggerTimes[valveId][TimingIntervals::MAX_VALVE_ERROR_HISTORY - 1] = millis();
  }

  // Use runtime-editable limits from ConfigState.
  const bool isPh  = (valveId % 2 == 0);
  const int  limit = isPh ? config.phMaxTrig : config.orpMaxTrig;

  // Select the error window for the valve type being checked.
  // pH and ORP now have independent windows defined in Config.h so they
  // can be tuned separately without affecting each other.
  const unsigned long errorWindow = isPh
    ? TimingIntervals::PH_VALVE_ERROR_WINDOW
    : TimingIntervals::ORP_VALVE_ERROR_WINDOW;

  if (count >= limit)
  {
    unsigned long oldest = valveTriggerTimes[valveId][count - limit];
    if (millis() - oldest < errorWindow)
    {
      if (!config.valveErrorLocked[valveId])
      {
        config.valveErrorLocked[valveId] = true;
        sd.logValveLocked(valveId);
      }
    }
  }
}

// ── resetValveErrors ──────────────────────────────────────────────────────────
void resetValveErrors()
{
  for (int i = 0; i < ValveMappings::TOTAL_VALVES; ++i)
  {
    config.valveErrorLocked[i] = false;
    valveTriggerCounts[i]      = 0;
    queued[i]                  = false;
    dwellTimer[i].stop();
    dwellRunning[i]            = false;
    // Stop the cooldown so valves can re-trigger immediately after a reset.
    // ActionTimer::done() returns true when not running, so stop() is all
    // that is needed — no separate "clear" is required.
    cooldown[i].stop();

    for (int j = 0; j < TimingIntervals::MAX_VALVE_ERROR_HISTORY; ++j)
      valveTriggerTimes[i][j] = 0;
  }

  mcp.resetState(queued);
  config.requestResetErrors = false;
}
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

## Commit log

2025-05-09 Reconstructing folder structure
    [BioReactor.fzz]
2025-05-09 Fix: remove submodule and add Code as regular folder
    [BioReactor.ino, pHCode.ino, sketch_may1a.ino]
2025-05-16 Merged feature
    [BioreactorPCB.kicad_pcb, BioreactorPCB.kicad_sch]
2025-05-25 Added calibration menu logic, pre-modularization
2025-05-29 Updated LCD menu
    [BioreactorPCB.kicad_sch]
2025-05-29 Moved everything over to arduino nano
2025-06-16 Pushing code for selenoid valve
    [BioreactorPCB.kicad_sch]
2025-06-25 Altered joystick setup for nano esp32
2025-06-25 Adjusted analog range for 3.3V bounds
2025-06-27 Updated LCD logic and added orp calibration
2025-06-30 Added basic valve logic and sd/time code
2025-07-02 Added a valve class
2025-07-19 Added SD valve updates, fixed orp done button, added valve error based on count, refactored feature2 code
    [BioReactorFeature.ino, Config.h]
2025-07-29 Replaced global variables with a stuct
    [Config.h, Sd.cpp]
2025-07-29 Created timer class
2025-07-29 Refactored loop using timer
2025-07-29 Reworked global blink function
    [Config.h]
2025-07-29 More refactoring, generated a test message function to replace delays
    [Config.h]
2025-08-05 Fixed bootup lcd format, removed some debounce delays, printed cal menu
    [Config.h, Sd.cpp]
2025-08-08 Added fsm to probes for non blocking logic
2025-08-08 Renamed state to probe state, fixed brace indentation, removed menu globals
2025-08-29 fixed menu exit button
2025-09-03 Fixed orp probe type issue, reformatted src
    [BioReactor.ino, BioReactorFeature.ino, Config.h]
2025-09-03 Temp rename to force case change
    [BioReactor.fzz, BioreactorPCB.kicad_pcb, BioreactorPCB.kicad_sch]
2025-09-03 Rename Diagrams -> diagrams (lowercase)
    [BioReactor.fzz, BioreactorPCB.kicad_pcb, BioreactorPCB.kicad_sch]
2025-09-22 Fixed valve issues
2025-11-25 probe expansion
2025-11-27 valve updates
2026-02-17 updated reactor diagram
    [BioReactor.fzz]
2026-02-27 Began standardized commenting, fixed lcd ph display issue
    [Sd.cpp, Sd.h]
2026-04-17 Added reset state after error lockout
    [BioReactor.fzz]
2026-04-23 Update README.md
    Added required libraries and Pin Numbering setting.
2026-08-10 Added function and fixed bugs 8/9/26
    Added functions to edit pH and ORP setpoints in the menu.
    Added functions to edit the maximum triggers of pH and ORP valves in an hour.
    Added different queues for pH and ORP valves.
    Fixed bugs that would cause unsuccessful calibrations due to incomplete data string sent from Atlas boards to the Arduino
    Fixed bugs that would cause random erroneous readings of pH and ORP data due to incomplete data string.
    Code has been tested with two full experimental runs
    [BioReactor.ino, Config.h]
2026-08-19 WiFi time sync
    The system automatically connects to WiFi and syncs time. Added a setting option to show the MAC address and sync time manually. It also shows when the last time-syncing event was. Also adjusted menu hierarchy to make error resetting and valve manual control easier. Finally, renamed the threshold setting to pH/ORP valve setting.
    [BioReactor.ino, Config.h, Sd.cpp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]
